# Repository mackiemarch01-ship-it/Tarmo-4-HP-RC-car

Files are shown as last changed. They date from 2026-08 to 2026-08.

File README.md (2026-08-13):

# Tarmo 4 HP V2.1

### Tarmo 4 high performance V2.1

### DISCLAIMER

This project is a derivative work based on Tarmo 4 and Tarmo 5, 
originally released under CC BY-NC-SA.

Modifications include:
- Reinforced chassis
- Updated suspension geometry
- High-performance drivetrain configuration
- Much more

Please visit the Links section at the end for links to Tarmo 4 and Tarmo 5. 

This project is not affiliated with or endorsed by the original creator.

⚠️ **Project Status: Work-in-Progress**  
This is a high-performance RC car that works, but has known issues (see below).
**Print at your own risk** — some parts may require iteration.

### Purpose: 

To test out the limit of 3D printed RC cars and to design a high performance version of the Tarmo chassis. 

### Changes:

1. **Stronger motor** I replaced the original motor (a D3542) with a high power hobbywing 4274 that can do 150A at 6S. This not only allows the car to be able to go faster but it opens a whole range of other possibilities for other motors eg. sensored setups for better torque and acceleration or even a dual motor setup. It also comes with its own adaptor and mount. 
2. **Enlarged chassis** With a larger power system and drivetrain comes a longer chassis. The chassis length has increased from 359mm to 470mm and the width has also been increased to roughly the same as the original suspention. 
3. **Remade shafts** The driveshafts are now much thicker and can be printed horizontally, meaning that it does not have to be printed out of TPU again. Everything now uses 15x24x5 bearings which not only increases the overall strength of the setup but also makes sourcing parts less complicated. The gears are also partly redesigned to allow it to fit with the new shafts. Furthermore this also eliminates the weak point that is the input gear for the diffs.
4. **Gear ratio change** The overall gear ratio has been changed to 1:2 because i made the central gears 1:1. I made this change to allow for higher speeds because a 4274 should have no problem pulling the car with is being quite light (2-3kg lighter than a Arrma limitless i believe).
5. **Gear changes** I also changed the middle gears since in testing they kept stripping hence i increased their modulus. I also increased tolerances so that the entire drivetrain spins much smoother. 
6. **Changes specifically for 3D printing** Most of the parts on the car can now be printed with no supports (or with easy to remove sacraficial supports) except for the central gearbox lid (minimal supports), the rear diffs, the front suspention mount and the driveshafts. Even those that do require supports require only a small amount (except for the driveshafts and the rear diffs) and can easily be removed by hand. I am currently working on removing them or designing small sacraficial supports directly into the model. 
7. **CV joints** I copied the Tarmo 5 CV joints over and slapped them on it since i believe they are designed beautifully and it would be a shame not to put them on. It also solves the reliability issue of dogbones that i was experiencing during previous testing. I also changed out the shaft in the middle of the Tarmo 5 Cvs with my own beefier design. I then thickened the CVs to about twice the thickness to increase strength and standardise the bearings so that only one type of bearing is needed throughout. The CVs even though after the change are still too thin and broke once after I tried to do a very fast drift. 
8. **Suspension changes** I thickened the kunckles to accomodate larger CVs and also to strengthen the entire thing after several failures of the CV joints.
9. **Bar in the middle** There is now a detachable bar in the middle in order to make the car chassis stiffer. I originally made it so that it is one part with the central gearbox lid but then changed it so that it is detachable that way iteration is easier.
10. **Others** Integrated gopro mount, integrated batter mount, integrated ESC mount (not taped on anymore!), proper steering links (not 3D printed), redesigned front wheel mounts (easier to print and more reliable), a bar to make the chassis stiffer, a dedicated wheel mounting thing for Arrma Dboot tyres and so much more.

For more information on specific changes and how the design evolved over time, see the changes section. 

### How can you build one? 

Here are 5 easy, no-nonsense steps that you can follow to build it. If you follow the steps carefully it should be quite easy to build (i spent so much effort on making sure that the tolerances are right and to simplify the build process). 

##### Step 1: Make sure you own a 3D printer with the right specs
- minimal 256x256x100mm build area (standard bambu lab size)
- can do nylons (~280 nozzle, ~100 bed, ideally enclosed)
- calibrated (important, make sure to do flow calibration as well to make sure tolerances are all right)
- can do CF and GF filled abrasives (hardened steel / gemstone nozzle) (i have a hardened steel one and a obxidian one)
If your 3D printer passes all those criteria, you are good to go!

##### Step 2: Make sure you have the right equipment
Here is a quick rundown:
- 3mm and 3.5mm allen key
- electric screwdriver that can do M3 and M4 SHCs (this is a NECESSITY trust me)
- pliers to remove supports (preferably one that has a pointy tip)
- Flat ground to run it (300m or longer if you want peak performance, no people)

##### Step 3: Source all the stuff (look at the BOM)
Visit the [BOM](https://docs.google.com/spreadsheets/d/1BZxuC8v3igST73ZecLRY6bIY1QTDZrayUpRSoW6Ge5I/edit?usp=sharing) for more info. The BOM should have all the info that you need when sourcing the parts. Make sure that you check that you have all of the stuff bought since there is nothing worse than sitting in front of a almost finished car that cannot run because one bearing is missing. 

##### Step 4: Print everything
Visit the printing guide for more information. Should take ~2d of printing on a X1 Carbon. 

##### Step 5: Assemble and troubleshoot
Follow the manual step by step and you should be fine. The manual should guide you from having a big pile of random stuff in front of you to having a working RC car that drives (hopefully since i am doing more testing). 

### Current problems

1. **Cogging** The motor cogs like nothing else at startup. It functions normally after cogging for a little while but sometimes it cogs a lot and is unable to start. There might be something wrong with the ESC settings (Punch is too high?) and I don't have a program card. The car is already geared up really high so lowering the punch and allowing for a gentler startup may help.
2. **CVs snap** The CVs albeit thicker still have the problem of snapping all the time since it is printed vertically hence the layer lines are screwing it up. I think this is a fundamental limitation of 3D printing and I don't have the ability to come up with a super creative idea to solve it.
3. **Tolerances** 3D printing is a fundamentally not so precise process like CNC machining so tolerances are extremely important. Too tight and eg. the gears bind and the car does not start and too loose everything just refuses to assemble tightly together. I have ironed out a lot of tolerances although it is still a prominent issue. This also highlights the importance of tuning your printer properly. (my printers are actually not so greatly tuned)
4. **Gopro mount** The gopro mount which i tried to design is absolutely horrible and snaps all the time along the layer lines. Even if it doesn't snap it is still horrible since the high g forces make the camera tilt forwards and backwards. Maybe you can help?
5. **Lack of Aero** This is pretty self explanatory as the car currently does not have a proper shell and is just running naked which produces tons of drag. I suck at surface modelling hence everytime I try to design an aerodynamic shell it fails miserebly. This is just a bone that I will have to bite though so stay tuned for any updates.
6. **Unstable** The car is pretty unstable due to the front steering being not perfectly square. This is primarily due to the threaded rods being too short and is a fairly easy fix.
7. **No heat set inserts** The car currently has no heat set inserts which is good for simplicity but terrible when it comes to basically any other aspects. One of the main consequences of this is that parts of the car just either spontaneously comes off or things get wiggly over time. I am currently working on it and stay tuned for updates.

### Background and inspirations

I started this project officially around a year ago because I ran out of stuff to do on a Sunday afternoon. I've had this project idea ever since I started getting into RC cars which is a long time ago and I got inspired to make my own design by Michael Rechtin's high speed RC car project (linked below) and I thought it was an absolute shame that he discontinued it and I decided that I would build a similar project and continue it in my own way. 

### Links

##### Onshape link:
[Link](https://cad.onshape.com/documents/9bbde2915b58dcc5d394239b/w/76bc731649daaa891173c7ea/e/1cbc67c5c6dc1ce02f15dc2f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)

##### Build guide:
[Link](https://docs.google.com/document/d/1ct8zCZzM1krHP-Pp0RBTua_wGqpxRtsJ6s1tjubo5Lw/edit?usp=sharing)

##### BOM:
[Link](https://docs.google.com/spreadsheets/d/1BZxuC8v3igST73ZecLRY6bIY1QTDZrayUpRSoW6Ge5I/edit?usp=sharing)

##### Tarmo 4:
[Thingiverse](https://www.thingiverse.com/thing:4178426)

##### Tarmo 5:
[Thingiverse](https://www.thingiverse.com/thing:5712880)

### License

This project is a derivative work based on Tarmo 4 and Tarmo 5, 
originally released under CC BY-NC-SA 4.0.

This project is licensed under the **Creative Commons Attribution-NonCommercial-ShareAlike 4.0 International License (CC BY-NC-SA 4.0)**.

You are free to:
- Share — copy and redistribute the material
- Adapt — remix, transform, and build upon the material

Under these terms:
- **Attribution** — You must give credit to the original Tarmo creators AND this derivative author
- **NonCommercial** — You may NOT use this material for commercial purposes
- **ShareAlike** — You must distribute your modifications under the same license

Full license text: https://creativecommons.org/licenses/by-nc-sa/4.0/

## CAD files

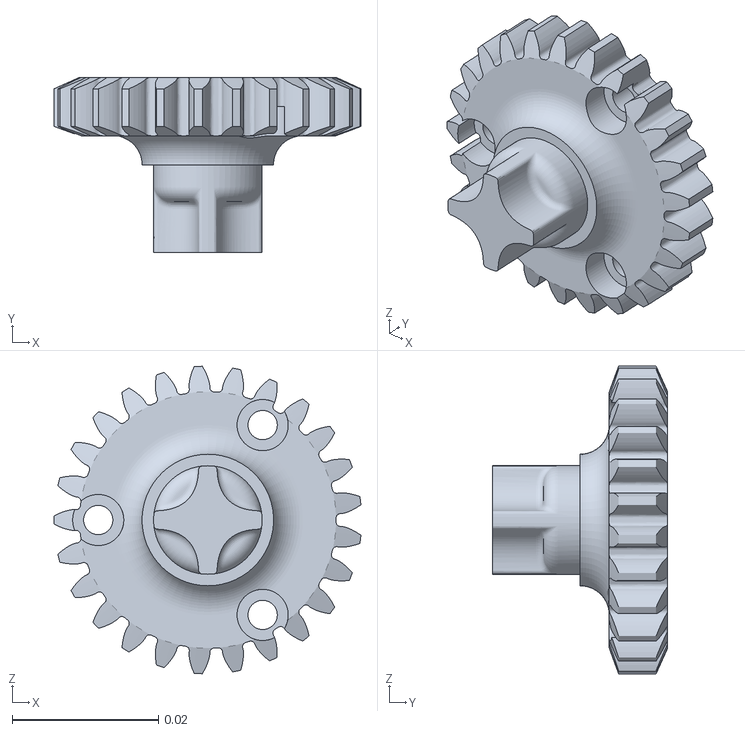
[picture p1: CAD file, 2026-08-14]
Chassis/Output gear - 2.stl
0.042 x 0.024 x 0.0421

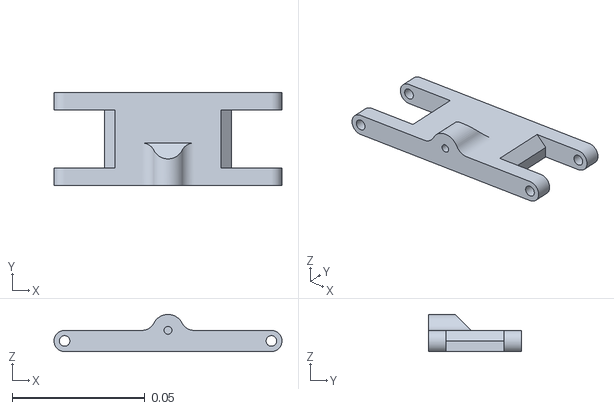
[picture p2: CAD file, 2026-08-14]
Front & Rear assembly/Lower Control Arm - 17A.stl
0.086 x 0.035 x 0.014

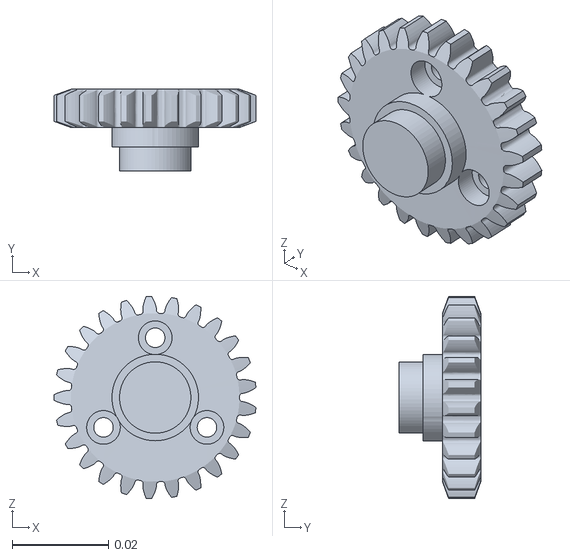
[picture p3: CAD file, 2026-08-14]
Chassis/Input gear - 2.stl
0.042 x 0.017 x 0.0421

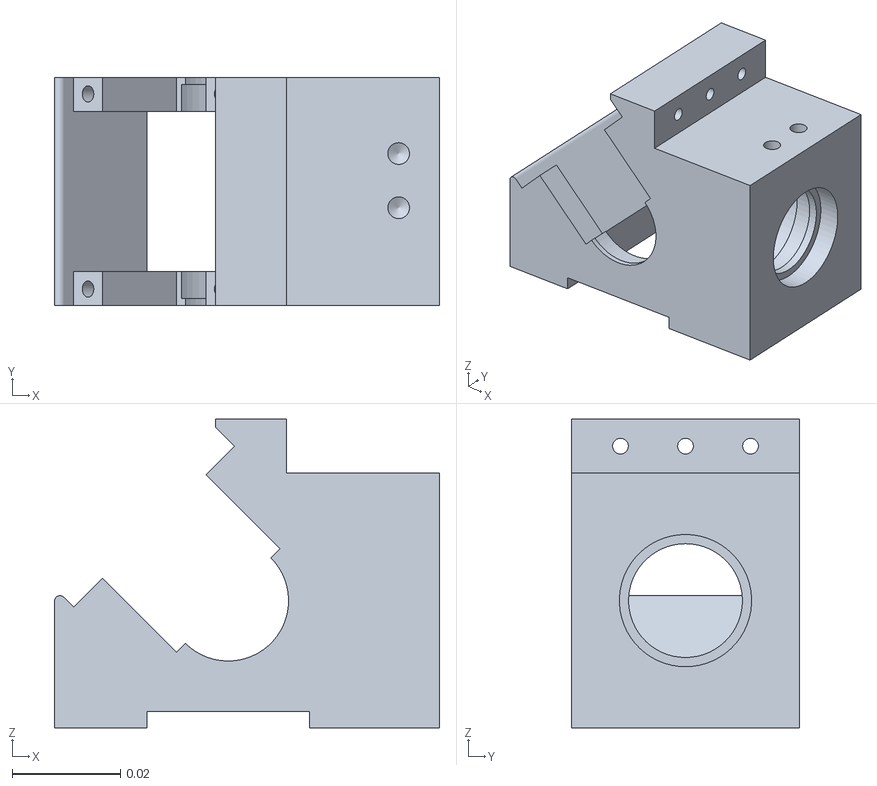
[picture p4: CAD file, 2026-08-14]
Front & Rear assembly/Rear Diff Gearbox - Gearbox.stl
0.071 x 0.042 x 0.057

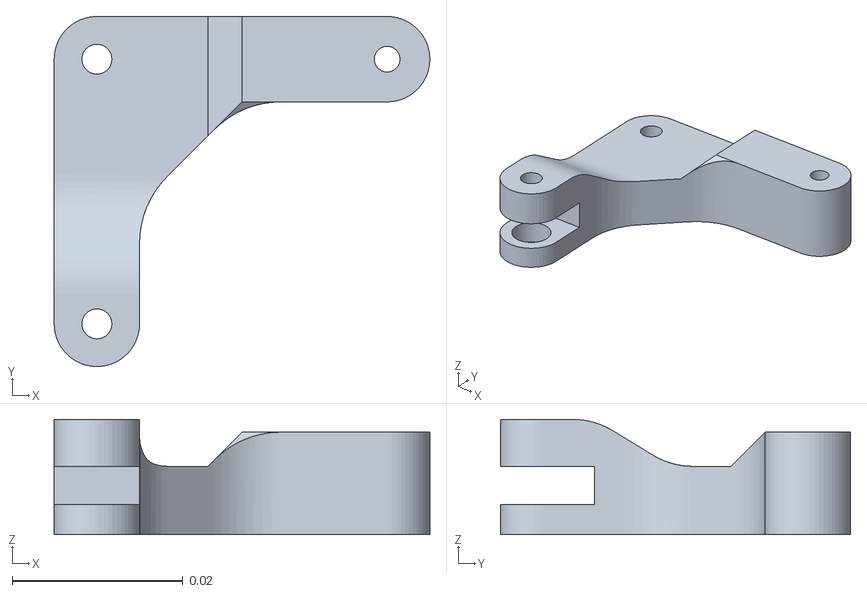
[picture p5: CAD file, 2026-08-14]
Chassis/Master Steering Arm - 20B.stl
0.044 x 0.041 x 0.0135

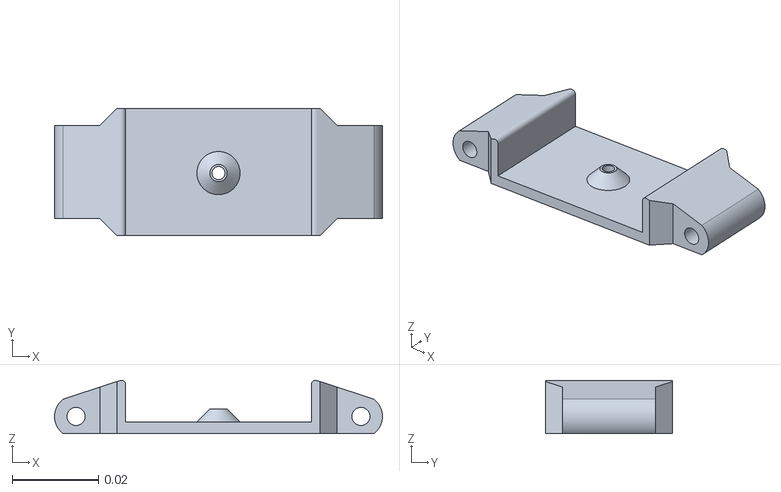
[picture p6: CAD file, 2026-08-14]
Front & Rear assembly/Lower Control Arm Mount (Rear) - 15A.stl
0.076 x 0.0295 x 0.0124

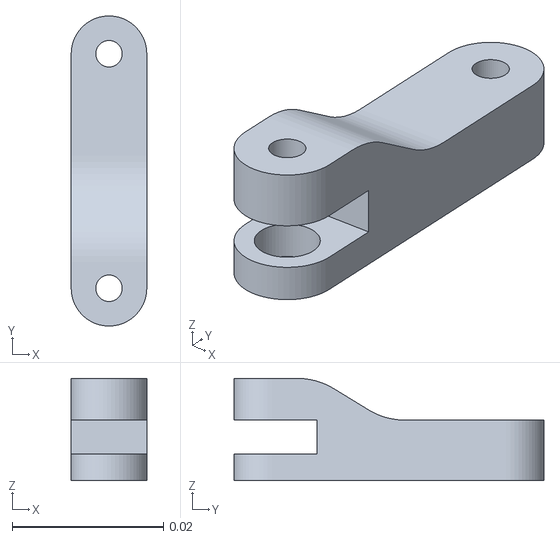
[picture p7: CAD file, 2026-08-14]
Chassis/Slave Steering Arm - 20C.stl
0.01 x 0.041 x 0.0135

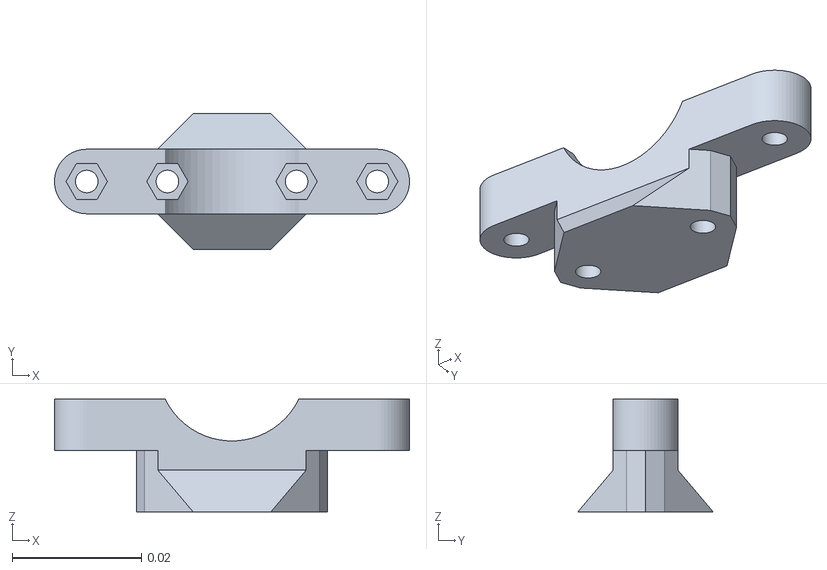
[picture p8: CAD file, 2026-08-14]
Front & Rear assembly/Steering Bracket - 05A.stl
0.055 x 0.021 x 0.0175

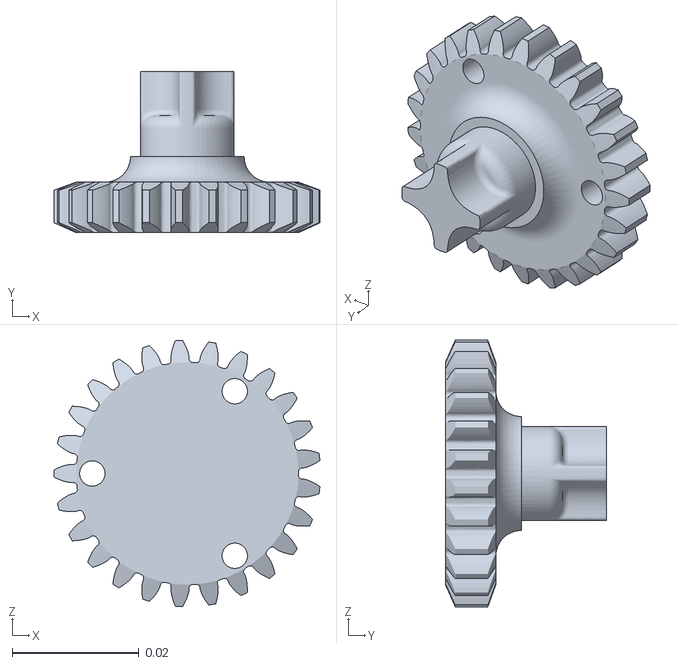
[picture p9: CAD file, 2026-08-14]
Chassis/Output gear - 1.stl
0.042 x 0.0255 x 0.0421

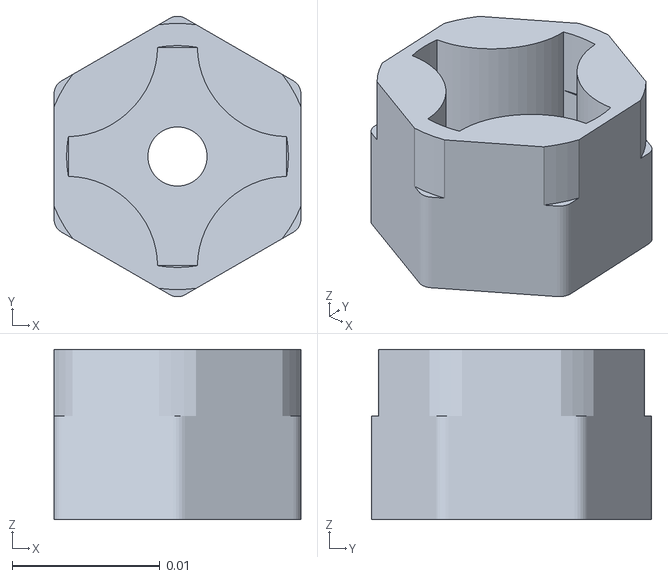
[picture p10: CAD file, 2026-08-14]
Front & Rear assembly/Wheel adaptor - Part 1.stl
0.0167 x 0.019 x 0.0115

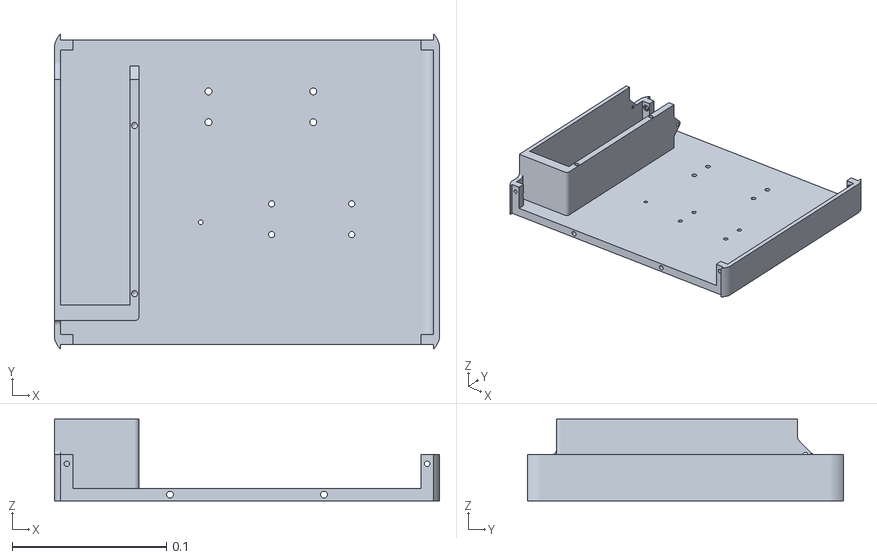
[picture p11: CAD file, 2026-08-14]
Chassis/Center Chassis - 02A.stl
0.25 x 0.205 x 0.053

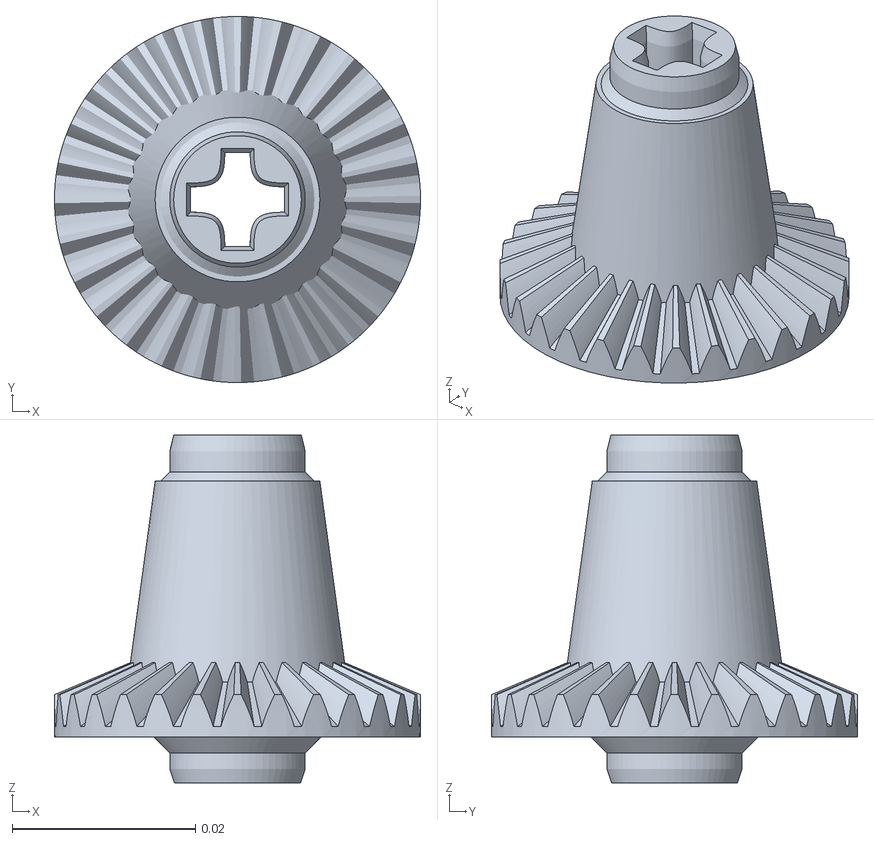
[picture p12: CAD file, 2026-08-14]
Front & Rear assembly/Locked Diff - Output.stl
0.04 x 0.04 x 0.038

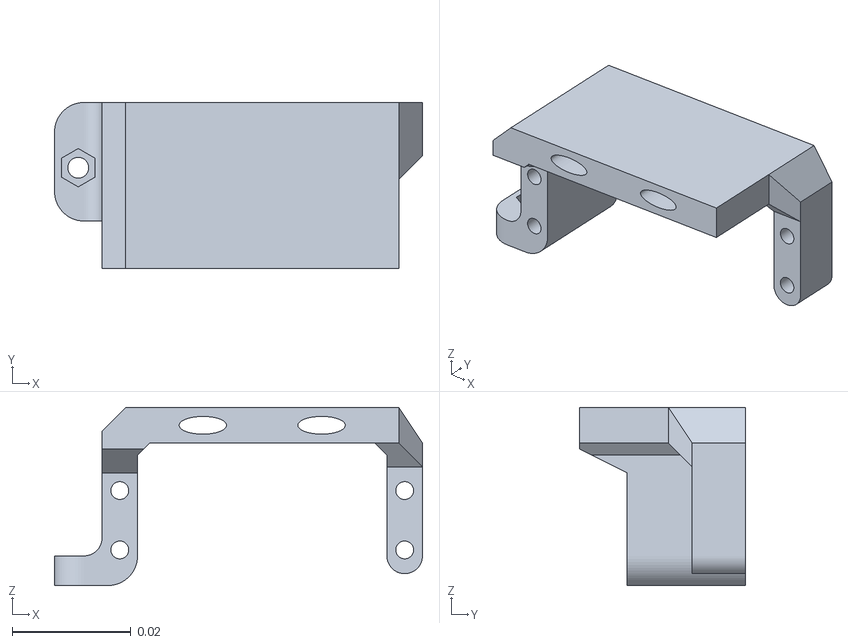
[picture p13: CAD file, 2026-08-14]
Chassis/Servo Mount - 07C.stl
0.062 x 0.028 x 0.03

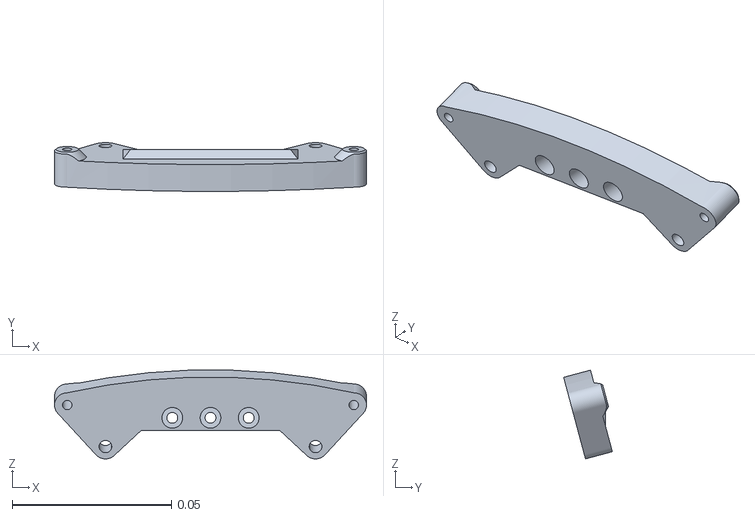
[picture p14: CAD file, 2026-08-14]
Front & Rear assembly/Shock Mount (Front) - 19A.stl
0.098 x 0.0153 x 0.0279

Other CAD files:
Chassis/Gearbox - Lid.stl
Chassis/Gopro mount.stl
Front & Rear assembly/CV CAGE.stl
Chassis/Front Chassis - 01A.stl
Chassis/Cover clip - Part 1.stl
Chassis/Front drive shaft - 10B.stl
Chassis/Gearbox - Base.stl
Chassis/Holder - Part 1.stl
Chassis/Input gear - 1.stl
Chassis/Motor mount - Part 1.stl
Chassis/Rear Chassis - 01A.stl
Chassis/Rear drive shaft - 10B.stl
Chassis/Steering Center Link - 20A.stl
Chassis/bar - Part 1.stl
Front & Rear assembly/Axle CV longer - C05-T.stl
Front & Rear assembly/Axle CV longer.stl
Front & Rear assembly/CV gear housing - C02.stl
Front & Rear assembly/CV inner race - C04.stl
Front & Rear assembly/Front Diff Gearbox - 03A.stl
Front & Rear assembly/Knuckle (Rear).stl
Front & Rear assembly/Locked Diff - Input.stl
Front & Rear assembly/Lower Control Arm Mount (front).stl
Front & Rear assembly/Nut for wheel - Part 1.stl
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
